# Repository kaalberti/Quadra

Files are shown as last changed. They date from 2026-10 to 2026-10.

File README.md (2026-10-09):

# Quadra

Active redesign: **ST3215 standard12V serial-bus servos +60 Wh conventional3S LiPo**.

- Current requirements/status:PROJECT.md and STATUS.md.
- Working leg CAD:mechanical/st3215-leg.scad; assembly preview:mechanical/st3215-leg.png.
- First-leg print/build instructions:docs/st3215-leg-build.md.
- Battery tray:mechanical/st3215-battery-tray.scad; provisional pack120 x50 x20 mm.
- Active single-servo feedback firmware: [bench guide](docs/st3215-feedback-bench.md), `firmware/st3215/`.
- Power/control architecture:electronics/st3215-power-plan.md.
- Buying list:docs/purchasing-bom.md; physical tests:PHYSICAL_TESTS.md.

These are untested working prototypes. Manufacturing/MFG-003 and existing
PWM firmware describe the previousMG996R design and are incompatible with
ST3215. Do not use them as the new build/programming instructions.

Read-only CAD artifact check: `node mechanical/verify-st3215-artifacts.mjs`.
Risk register and mitigation status: [design review](docs/design-review.md).

Verifier regression tests: `node --test mechanical/verify-st3215-artifacts.test.mjs` (in-memory changes; no CAD export).

- Complete working chassis assembly: [st3215-chassis.scad](mechanical/st3215-chassis.scad).
- Chassis build/layout: [build guide](docs/st3215-chassis-build.md).

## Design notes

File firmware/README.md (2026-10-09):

> ST3215 redesign: this is preserved MG996R/PCA9685 PWM firmware. It cannot control the selected serial-bus servos. Do not deploy it for the new leg. See ../electronics/st3215-power-plan.md.

Active ST3215 project: [st3215/README.md](st3215/README.md); [bench wiring/operation](../docs/st3215-feedback-bench.md).

# Individual-servo bench controller

FW-001 supports one explicitly armed servo at a time. This has been compiled
for the user-reported ESP32-S3 N16R8 (16MB flash/8MB OPI PSRAM), not flashed
or tested on hardware. The generic DevKitC pin mapping remains provisional.
Read ../electronics/bench-wiring.md first. Verify your actual board pins,
servo voltage and PSU capacity. Keep the servo rail OFF during setup/reset.

## Build and tests

The build wrapper refuses by default. For intentional MG996R/PCA9685 reference work only, use `firmware/build.ps1 -AllowLegacyPwm`; host tests remain `firmware/test.ps1`. The PowerShell console requires `-AllowLegacyPwm`, and direct Python console use requires `--allow-legacy-pwm`. These do not make this firmware compatible with ST3215. Direct PlatformIO/custom tools can bypass these entry-point guards.
For a new checkout on this Windows workstation, run
`firmware/setup-local-tools.ps1` first. It copies the existing PlatformIO
platform/packages locally and downloads the pinned, checksum-verified host
compiler if absent. It does not install PlatformIO globally. A different
workstation needs an existing compatible PlatformIO installation first.
The embedded build uses PlatformIO Core6.2.0 and project-local copies of
Espressif platform7.0.1, Arduino-ESP32 package3.20017.241212 and Xtensa
8.4.0. No third-party servo library is required. Wire is bundled with Arduino.
The local cache is ignored by Git; a clean checkout needs these build tools.

Host tests execute the same C++ controller, parser and PCA driver through
mock I/O. Portable Zig0.13.0 is used solely as a host C++ compiler, downloaded
from [the official distribution](https://ziglang.org/download/index.json).
Archive SHA256: d859994725ef9402381e557c60bb57497215682e355204d754ee3df75ee3c158.
All compiler/build caches stay in firmware/.pio-core or firmware/test-output.
Generated target: .pio/build/bench-s3/firmware.bin. No upload command is run.

## Serial commands —115200 baud, newline termination

| Command | Effect |
|---|---|
| `status` | Report state/fault/last channel and pulse; does not extend timeout |
| `arm 0` / `arm 1` / `arm 2` | From DISARMED, full-off all outputs, set selected channel1500us, then lower OE |
| `pulse 1450` .. `pulse 1550` | Change the armed channel within the narrow initial window |
| `keepalive` | Extend armed session if configuration and I2C are healthy |
| `disarm` | Raise OE immediately and write full-off; never clear a latched fault |
| `reset` | Raise OE and reinitialize; leave DISARMED if successful; rail OFF first |

An armed session requires a valid pulse or keepalive at least every1.5s.
Timeout, bus failure or invalid command while armed latches FAULT. Configuration
is checked every100ms while armed and before every move/keepalive. Recovery
requires diagnosis, physical power cutoff, then explicit reset and arm.
An arm command cannot change channels during an armed session; disarm first.
There are no joint-angle commands, calibration, IK, Wi-Fi or gait control.

Startup raises OE before I2C setup. The driver uses3.3V I2C at100kHz,
address0x40, MODE1=0x20 and MODE2=0x04. It programs prescale121 while asleep,
waits600us after waking, and individually full-offs all16 outputs before arm.
These sequences follow the [NXP PCA9685 datasheet](https://www.nxp.com/docs/en/data-sheet/PCA9685.pdf).
An existing sticky EXTCLK setting requires a PCA logic power cycle.

With a nominal25MHz oscillator, prescale121 yields50.0288Hz and4.88us/tick.
Requested1450/1500/1550us map to297/307/318ticks (1449.36/1498.16/1551.84us).
These are nominal values; measure actual PWM before widening travel or
attaching a horn. The narrow window is for an unmounted servo, not a known
safe range for the assembled leg. Register readback cannot verify physical
OE wiring, output pulse voltage, MCU lockup, or servo power/current.

Removing signals can leave a digital servo holding. Use the physical power
cutoff for isolation. No physical safety, fit or loaded-duty result is claimed.

## Supervised host console

Use the existing PlatformIO Python environment, for example:

```powershell
$env:PYTHONDONTWRITEBYTECODE='1'
& C:\Users\Kyle\.platformio\penv\Scripts\python.exe firmware/bench_console.py --port COM5 --allow-legacy-pwm
```

Substitute your verified port. Keep servo power OFF when opening the port:
some boards reset on serial connection despite DTR/RTS settings. The console
accepts a disarmed/faulted device and never arms automatically. A FAULT requires
diagnosis and the explicit operator command `reset rail-off`; this text is an
operator acknowledgement, not a voltage measurement.

Once `arm 0` is explicitly entered, the console sends keepalive every0.4s
while replies match the expected channel/pulse/state. `pulse 1450..1550`,
`status`, `disarm`, and `quit` are supported. Stay at the bench; console
keepalives continue while waiting for keyboard input. Use quit/disarm or the
physical cutoff before leaving. Loss of a reply within0.35s, unexpected state,
device reboot, invalid armed command or exit stops this session and attempts
disarm. It never reconnects or automatically recovers. If disarm cannot be
delivered, the MCU's1.5s command timeout remains the fallback.

Test without hardware:
`python -m unittest discover -s firmware/test -p test_console.py -v`.
These12 transport tests complement the12 C++ controller tests. The console
uses pyserial already present in the existing PlatformIO environment; it does
not enumerate/open ports during testing. No real serial session was performed.

## Offline calibration — FW-003

`include/joint_calibration.h` maps degrees to pulse width from two measured
anchors, in either direction. Usable angular limits must lie inside the anchor
interval; no extrapolation or silent clamping. Invalid/unmeasured profiles fail
without changing output. `joint-calibration.json` remains an unset recording
template, not loaded by firmware. No angle command is enabled on hardware.
Generic500..2500us validation bounds are only an absolute software screen,
not approved servo travel. Tests use synthetic profiles; never copy them to
hardware. Physical calibration and limits are listed in ../PHYSICAL_TESTS.md.

FW-007 adds `calibration_profiles.py` for measured JSON validation, offline
pulse previews and optional C++ header export. It requires all three measured
profiles and keeps every anchor/limit within1450..1550us. It never connects to
hardware or changes the firmware. The current unset template is rejected.
Workflow and commands: ../docs/measured-calibration-profiles.md.

FW-008 adds `offline_leg_plan.py` to run the existing C++ calibrated planner
against a requested foot reference position and explicit branch policy. It
returns a complete offline plan only if measured profiles, trial bounds and
bench pulse limits pass. Current unset records are rejected. No board connection
or powered commands are added. Workflow: ../docs/offline-leg-planner.md.

## Board-only diagnostic

`timing rail-off no-servos` is a manual serial-monitor command while DISARMED.
It temporarily drives only channel15 for3.3V timing capture on GPIO7, then
restores disabled/full-off outputs. FW-009 supports this explicit command in the
supervised console only while disarmed, with optional new-file `--timing-log`
JSONL capture. Do not run a serial monitor and console together. Wiring and limits:
../docs/board-pwm-timing-test.md. No physical capture or flash was performed here.

## Removable voltage diagnostic — ELEC-008

Manual serial command `voltage rail-off no-servos` works only while DISARMED.
GPIO8/ADC1_CH7 uses the provisional150k/10k perfboard divider and100nF filter.
Sixteen readings report nominal input voltage, ADC millivolts and sample spread;
no servo output is enabled and no battery cutoff is implemented. An armed
request trips the command fault. The input is not calibrated against physical
measurements and must be disconnected before ESP32 power is removed.
Wiring, voltage limit, buying delta and later comparison procedure:
[voltage input](../electronics/voltage-perfboard.md). No upload or powered test.

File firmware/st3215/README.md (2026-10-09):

# Active ST3215 bench firmware

Read [the wiring and operation guide](../../docs/st3215-feedback-bench.md).
This separate ESP32-S3 project supports single-servo ping, feedback and explicitly
acknowledged torque-off with readback. UART starts disabled. No motion, torque-enable,
broadcast or EEPROM command is exposed. Hardware testing and flashing remain pending.

Build: `./build.ps1`. Independent mock checks: `./test.ps1`.
Both reuse existing tools under parent `firmware/`; neither uploads firmware.

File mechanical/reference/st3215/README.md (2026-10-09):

# Public ST3215 reference files
Downloaded2026-10-09 from manufacturer wiki resource links:
- Drawing PDF/DXF:https://files.waveshare.com/upload/0/08/ST3215-2D.zip
- STEP:https://files.waveshare.com/upload/5/59/ST3215-3D.zip
- Linking page:https://www.waveshare.com/wiki/ST3215_Servo
The2022 drawing title isSCS215 despite its ST3215 resource filename/link.
Treat physical interfaces provisionally and check selected12V servo/wheel kit.
Working CAD uses a conservative envelope,not a claim of exact imported STEP fit.

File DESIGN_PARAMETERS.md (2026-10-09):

# Design parameters
Last updated:2026-10-09

## Robot and kinematics
LEGS = 4
DOF_PER_LEG = 3
DOF_TOTAL = 12
TARGET_OPERATING_MASS = 2.0 kg preferred
MAX_OPERATING_MASS = TBD; demonstrated servo/power duty
BODY_LENGTH = 175 mm PROVISIONAL
BODY_WIDTH = 160 mm PROVISIONAL
UPPER_LEG_LENGTH = 70 mm
LOWER_LEG_LENGTH = 85 mm
PROTOTYPE_J1_TO_J2_FORWARD = 85 mm PROVISIONAL
PROTOTYPE_J1_TO_J2_OUTWARD = 0 mm PROVISIONAL
PROTOTYPE_J1_TO_J2_VERTICAL = 0 mm
PROTOTYPE_NOMINAL_J1 = 0 deg
PROTOTYPE_NOMINAL_J2 = 44.0486 deg
PROTOTYPE_NOMINAL_J3 = 78.9786 deg
JOINT_LOADED_LIMITS = TBD
IK_BODY_FRAME = +x forward,+y left,+z up
POSITIVE_J1 = outward abduction
POSITIVE_J2 = upper leg forward
POSITIVE_J3 = knee flexion backward

## Actuator and mounting
SERVO_MODEL = ST3215 12V/30 kg.cm variant; user selected
SERVO_QUANTITY = 12
SERVO_CONTROL_INTERFACE = single-wire half-duplex TTL UART
SERVO_BUS_BAUD = 1000000 bit/s PROVISIONAL
SERVO_DRIVER = compatible TTL bus adapter; Waveshare Bus Servo Adapter A candidate
SERVO_OPERATING_VOLTAGE = 6..12.6 V manufacturer
SERVO_STALL_TORQUE_REFERENCE = 30 kgf.cm at12 V; not continuous torque
SERVO_STALL_CURRENT_REFERENCE = 2.7 A at12 V
SERVO_UNIT_MASS = TBD
SERVO_BODY_DRAWING_ENVELOPE = 45.22 x24.72 x35 mm PROVISIONAL
SERVO_SHAFT_OFFSET_FROM_END = 10.11 mm PROVISIONAL
SERVO_WHEEL_OD = 19.2 mm PROVISIONAL
SERVO_WHEEL_HOLE_PCD = 14 mm; four positions PROVISIONAL
SERVO_WHEEL_OVERALL_SPAN = 37.25 mm PROVISIONAL
SERVO_WHEEL_FACE_SYMMETRY = TBD
SERVO_WHEEL_SCREW_THREAD_AND_ENGAGEMENT = TBD
ST3215_FORK_INNER_PLANES = -23,+23 mm PROVISIONAL
ST3215_FORK_PLATE_THICKNESS = 5 mm
ST3215_WHEEL_FRONT_FACE_DISTANCE = 18.625 mm PROVISIONAL
ST3215_WHEEL_REAR_FACE_DISTANCE = 18.625 mm PROVISIONAL; positive magnitude
ST3215_WHEEL_FRONT_SPACER = 4.375 mm PROVISIONAL; 23 minus front face
ST3215_WHEEL_REAR_SPACER = 4.375 mm PROVISIONAL; 23 minus rear face
ST3215_CASE_CLAMP_POCKET = 25.52 x35.8 mm PROVISIONAL
ST3215_CLAMP_FIT_COUPON_GRIP = 29 mm PROVISIONAL
ST3215_CLAMP_FIT_COUPON_POCKET = 25.52 x29.8 mm PROVISIONAL
ST3215_CASE_CLAMP_SPLIT_GAP = 1 mm PROVISIONAL
ST3215_WORKING_CAD = mechanical/st3215-leg.scad
ST3215_LEG_PRINT_PIECES = 16 PROVISIONAL
PHYSICAL_FIT_VALIDATED = false
POWERED_LEG_VALIDATED = false
CURRENT_MANUFACTURING_PACK = NONE for ST3215

## Power
BATTERY_CHEMISTRY = conventional LiPo PROVISIONAL
BATTERY_CELL_COUNT = 3S
BATTERY_ENERGY = 60 Wh user reported
BATTERY_NOMINAL_VOLTAGE = 11.1 V PROVISIONAL
BATTERY_MAX_VOLTAGE = 12.6 V
BATTERY_CAPACITY = approximately5.4 Ah DERIVED; label unverified
BATTERY_DISCHARGE_RATING = TBD
BATTERY_DIMENSIONS = 120 x50 x20 mm PROVISIONAL user supplied
BATTERY_MASS = TBD
BATTERY_CONNECTOR = TBD
BATTERY_LOCATION = low central removable; actual packaging TBD
SERVO_POWER_ARCHITECTURE = protected switched3S battery bus
SERVO_SUPPLY_VOLTAGE = battery voltage; maximum12.6 V
SERVO_MAIN_DISTRIBUTION_CAPACITY_SCREEN = 40 A PROVISIONAL; not demand
SERVO_THREE_JOINT_STALL_SUM = 8.1 A reference
SERVO_TWELVE_JOINT_STALL_SUM = 32.4 A reference
MAIN_FUSE = TBD; coordinated with pack,wires,connectors
BRANCH_PROTECTION = TBD
LOGIC_SUPPLY = regulated5 V buck from3S; module TBD
LOGIC_VOLTAGE = 3.3 V ESP32
BENCH_SERVO_SUPPLY = 12.0 V PROVISIONAL one-servo tests
AVAILABLE_BENCH_SUPPLY_MAX_VOLTAGE = 60 V user reported
AVAILABLE_BENCH_SUPPLY_CURRENT = 5 A user reported
BATTERY_SOFTWARE_STOP_THRESHOLD = 10.5 V PROVISIONAL loaded
BATTERY_WARNING_THRESHOLD = 10.8 V PROVISIONAL
BATTERY_CELL_MONITOR = 3S balance-lead alarm; threshold/part TBD
BATTERY_PROTECTION_IMPLEMENTED = false

## Electronics and sensors
MCU = ESP32-S3
OWNED_MCU_BOARD = ESP32-S3 N16R8; header layout unverified
OWNED_PWM_BOARD = Adafruit PCA9685; unused in current actuator design
SERVO_BUS_GPIO = TBD
SERVO_BENCH_GPIO_ALLOWED = distinct GPIO4..7; manual selection with rail off
SERVO_BENCH_CAPABILITY = ping/feedback/torque-off readback only; no motion
SERVO_BENCH_PHYSICALLY_VALIDATED = false
SERVO_IDS = FL1..3; FR4..6; RL7..9; RR10..12 PROVISIONAL
IMU = 6-axis breakout TBD
RANGE_SENSOR = forward ToF breakout TBD; later stage
ELECTRONICS_PROTOTYPE_ASSEMBLY = perfboard and modules
ELECTRONICS_FINAL_ASSEMBLY = SMT consideration; TBD
ELECTRONICS_PREFERRED_SUPPLIER = DigiKey
CUSTOM_PCB = DEFERRED
VOLTAGE_DIAGNOSTIC_DIVIDER = 150 kOhm /10 kOhm,100 nF PROVISIONAL
VOLTAGE_DIAGNOSTIC_GPIO = 8 PROVISIONAL
VOLTAGE_DIAGNOSTIC_INPUT_RANGE = 0..25.2 V positive; manual power sequencing only
VOLTAGE_DIAGNOSTIC_PHYSICAL_CALIBRATED = false

## Printing and budget
AVAILABLE_PRINTER = Creality K2 Pro user-reported access
NOZZLE_DIAMETER = 0.4 mm
LAYER_HEIGHT = 0.2 mm
PRIMARY_MATERIAL = PLA+ /PETG
DEFAULT_STRUCTURAL_WALL = 3 mm PROVISIONAL
DEFAULT_JOINT_FASTENER = M3
TOTAL_REV_A_BUDGET_TARGET = NZ$500–800
TOTAL_REV_A_BUDGET_MAX = NZ$1000
SERVO_UNIT_COST_TARGET = NZ$25–35
SERVO_UNIT_COST_SOFT_MAX = NZ$50
ACTUATOR_TOTAL_TARGET = NZ$300–420
ST3215_LANDED_PRICE = TBD

BATTERY_TRAY_INTERNAL_ENVELOPE = 122 x52 mm PROVISIONAL
BATTERY_TRAY_PRINT_ENVELOPE = 134 x66 x11 mm
BATTERY_TRAY_PADDING = 1 mm PROVISIONAL
BATTERY_TRAY_STRAPS = 2 reusable15 mm straps; length >=250 mm PROVISIONAL
BATTERY_TRAY_MOUNTING = fourM3 holes; chassis placement TBD

## ST3215 chassis layout
CHASSIS_CAD = mechanical/st3215-chassis.scad
CHASSIS_HIP_ORIGINS = FL[115,50,0];FR[115,-50,0];RL[-115,50,0];RR[-115,-50,0] mm
CHASSIS_FRONT_LEG_YAW = 0 deg
CHASSIS_REAR_LEG_YAW = 180 deg
CHASSIS_OUTWARD_J1_SOURCE_SIGN = FL+;FR-;RL-;RR+
CHASSIS_PRINT_ENVELOPE = 175 x160 x42 mm
CHASSIS_FLOOR_Z = -48..-43 mm
CHASSIS_WALL_THICKNESS = 5 mm
CHASSIS_HUB_RELIEF_DIAMETER = 34 mm
CHASSIS_DECK_ENVELOPE = 140 x140 x4 mm
CHASSIS_DECK_UNDERSIDE_Z = 8 mm
CHASSIS_RISERS = four10 mm diameter x51 mm; M3 bore
CHASSIS_BATTERY_CENTER = [0,0,-29] mm PROVISIONAL
CHASSIS_BATTERY_TO_DECK_CLEARANCE = 27 mm PROVISIONAL; no leads
CHASSIS_NOMINAL_FOOT_REFERENCE_SPACING = 400 x100 mm
CHASSIS_NOMINAL_FLOOR_GROUND_CLEARANCE = 72 mm; excludes hardware/pads
CHASSIS_SOLID_PETG_MASS = approximately331 g DERIVED; excludes legs/tray/hardware
CHASSIS_PHYSICAL_VALIDATED = false
ROBOT_INSTALLED_PRINT_PIECES = 71 PROVISIONAL; includes battery tray

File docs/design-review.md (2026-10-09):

# Current design review — ST3215 / 3S prototype

Reviewed: 2026-10-09. Scope: current printable one-leg CAD, provisional battery
tray, power/control plan, buying BOM, validation checker and physical-test plan.
This register records findings; it does not approve hardware for powered use.

The architecture is a plausible affordable prototype direction. Its main gaps
are real servo interfaces, protected electrical implementation and control
firmware. Additional detailed structural analysis is unlikely to help as much
as testing one servo kit and one printed leg. A complete walking robot has not
yet been designed or qualified.

## Evidence and limits

- [Leg CAD](../mechanical/st3215-leg.scad), [build guide](st3215-leg-build.md)
  and [validation report](../mechanical/st3215-leg-check.json): eight leg meshes and two alternative fit coupons, axis/contact checks and three sampled collision poses passed.
- [Battery tray](../mechanical/st3215-battery-tray.scad) and
  [tray guide](st3215-battery-tray.md): printable geometry, not verified pack fit.
- [Power plan](../electronics/st3215-power-plan.md), [BOM](purchasing-bom.md)
  and [physical tests](../PHYSICAL_TESTS.md): planned components and tests,
  not implemented protection, actual current measurements or completed tests.
- Current report hashes match both CAD sources, the validation generator, ten part/coupon STLs and tray STL.
  This checks artifact identity; it does not repeat or extend the CAD checks.
- No servo, battery, print, firmware or loaded leg has been physically validated.

## Risks and checks

Priority is the milestone affected, rather than a speculative numerical score.
A later-stage issue does not block current documentation or a cheap fit coupon.

| ID / resolve before | Evidence and risk | Consequence | Smallest useful check or action |
| --- | --- | --- | --- |
| R1 — bulk leg printing | Clamp pocket defaults to 35.8 mm while the referenced main shell band is about 29 mm; drawing-to-actual case shape remains uncertain. The 1 mm split cannot close that difference. Short tail grip also depends on friction and print creep. | Loose servo, crushed case if overtightened, or blocked connector. | Obtain one kit; measure the actual grip band and ports; print one clamp coupon. Adjust the grip parameter or use fitted liners, then check retention without case distortion. |
| R2 — assembled powered leg | Rear wheel/support behavior, wheel face positions and supplied screws are unverified. Front/rear spacers now adjust independently; their default 4.375 mm values still assume symmetric faces. | Binding, bearing preload, stripped threads or a fork attached to a stationary case feature. | Verify both output interfaces; measure each side separately; hand-assemble a fork with correct screw engagement and free movement before power. |
| R3 — motion beyond sampled poses | Collision checks cover three poses and simplified bodies; they omit real cable bends, protruding fasteners and spacer-ring interactions. | Cable damage or a hard mechanical stop while the motor drives. | Route actual cables; move the supported unpowered leg through a conservative intended range; establish limits from observed clearance. Check additional CAD poses only where useful. |
| R4 — loaded leg | Long hip bridge, fork plates and tail clamps have no printed/load evidence. Layer direction, support removal, bolt tightening and warm plastic can affect stiffness. | Deflection, slipping joints or print failure despite a valid STL. | Slice with suitable orientation/supports; inspect the first prints, then apply representative supported foot load and check movement/loosening. Revise locally if needed; no FEA required now. |
| R5 — battery-powered multi-servo test | 60 Wh and the assumed pack size do not establish discharge rating, cell balance, mass or condition. | Excessive sag, hot wiring or damaged cells. | Read the actual label/specification, inspect and balance-check the pack; verify connector ratings and measure staged load/sag. Use a compatible balance charger. |
| R6 — any powered test; scale before multiple servos | Harness, fuses, switch and buck are not selected. The proposed adapter is rated only 5 A; one-leg stall reference is 8.1 A. Three-wire injection can accidentally put aggregate current through small cables. | Overheated connectors/board, shorts or MCU damage. | Fuse the initial single-servo setup; verify polarity/pinout. Design rated parallel power branches with a shared signal ground and explicit injection wiring before scaling. Do not use adapter/perfboard as the main power distributor. |
| R7 — unrestricted battery motion | Full 3S charge is 12.6 V, equal to the published servo upper operating limit. Regeneration/transients and logic supply behavior are untested. | Servo overvoltage, resets or uncontrolled commands after brownout. | Start at current-limited 12.0 V on the bench; verify separate logic regulation and USB/power paths. Investigate supply excursions during starts/stops before unrestricted battery use; a multimeter alone cannot establish fast peak voltage. |
| R8 — unattended or prolonged battery operation | No low-battery protection works yet. Pack voltage can hide a weak cell. Existing manual ADC sense requires sense-positive disconnection before MCU power-off. | Overdischarge or back-powering an unpowered ESP32 input. | Use individual-cell monitoring and manual observation initially; implement supported low-battery stop and safe off-state sensing before leaving the pack connected. Qualify thresholds against the actual pack. |
| R9 — first commanded motion | Legacy firmware drives PWM servos. Separate ST3215 feedback/off bench is compiled and mock-tested; motion, direction, offsets, joint limits and powered fault behavior remain unimplemented/unverified. Default IDs may conflict; lost communication behavior is unqualified. | Unexpected movement, continued holding/heating, or collapse on torque removal. | Commission one unmounted servo and one unique ID at a time. Verify feedback, startup, timeouts, recovery and torque release; support the leg/robot during calibration and shutdown. |
| R10 — choosing final mass or walking duty | Stall torque is not a continuous torque rating. Current total robot mass and sustained demand at discharged-pack voltage are unknown. | A robot that stands briefly but overheats, sags or cannot walk reliably. | Weigh the actual assembly; perform one useful stance torque estimate and supported loaded-leg duty test. Adjust stance/geometry or mass if measurements require it; do not treat 2 kg as a qualified limit. |
| R11 — standing on four legs | A working ST3215 chassis/rotated leg layout now exists with provisional battery/board spaces and geometric four-foot support. Actual mass/COM, hardware fit and loaded motion remain untested. Flat foot contact is aligned to the nominal stance only. | Inter-leg interference, tipping, insufficient ground clearance or edge contact/slip. | Lay out four legs and actual masses, revise kinematics for the new datum, and check a simple supported stance/weight shift before crawl. Test inexpensive foot pads if slipping appears. |
| R12 — relying on automated qualification | Link/hip dimensions now drive geometry and parameter perturbations are checked. Nominal pose qualification and some fixed interface dimensions remain deliberately specific to this revision. Tray source and generator are now hash-bound; full swept and physical qualification remain outside these checks. Existing legacy firmware/release outputs remain in the repo. | A future edit or old workflow can appear valid while describing different hardware. | Read-only artifact verification and explicit legacy build/console guards are implemented. Keep geometry/checks coupled when revising CAD; use fit checks after exports. Direct PlatformIO invocation or custom serial tools can bypass these entry-point guards. |
| R13 — ordering all twelve servos | Exact variant, kit contents and landed NZ cost are not confirmed. Quantity multiplies small price differences; power hardware and charger add cost. | Budget overrun or twelve incompatible kits. | Confirm standard 12 V variant and wheel kit with one sample, then price the complete quantity-adjusted BOM including freight/tax before bulk ordering. No supplier contact is needed for this review. |

Manufacturer basis for R6: [Bus Servo Adapter A FAQ](https://docs.waveshare.com/Bus_Servo_Adapter_A/FAQ)
states 5 A maximum board current, no onboard voltage regulation and unique servo
IDs. This supports the existing separate power-distribution direction.
Manufacturer basis for R7/R10: [ST3215 documentation](https://www.waveshare.com/wiki/ST3215_Servo)
and [product specifications](https://www.waveshare.com/product/st3215-servo.htm).
The standard 12 V model lists 6–12.6 V operation, 30 kgf.cm stall torque and
2.7 A stall current at 12 V. These are reference limits, not measured robot duty.

## Assumptions to keep explicit

| ID | Working assumption | How it will be resolved |
| --- | --- | --- |
| A1 | Standard 12 V ST3215, not the 7.4 V or HS variant; published drawing/model matches the purchased kit. The downloaded drawing is labelled SCS215 despite its ST3215 filename. | Compare one actual kit with the drawing and CAD before repeated prints/orders. |
| A2 | Both sides provide compatible wheel interfaces usable for the supported fork; actual kit includes suitable wheels/fasteners. | Inspect rear support behavior and supplied hardware; do not infer it from the case boss alone. |
| A3 | Conventional 3S LiPo, about 60 Wh; 120 x 50 x 20 mm is only the provisional pouch envelope. | Measure label, pack, leads and connector; record mass, condition and discharge rating. No LiHV substitution. |
| A4 | 70/85 mm links and 85 mm hip forward offset provide useful first-leg geometry; nominal foot axial datum is now 0 mm. | Test one leg and then check complete chassis packaging and calibrated kinematics. |
| A5 | Printer/material tolerances, support removal and plain bolt hardware allow the proposed fit. | Slice and print coupons/first parts; inspect actual clearances and tightening stack. CAD fit is not printer fit. |
| A6 | Extra weight is acceptable only where loaded servo/current/temperature tests support it. | Maintain an actual mass tally. Old MG996R mass estimates do not qualify the new robot. |
| A7 | Initial operation is remotely commanded, slow and on a level indoor surface. | Validate static stance and crawl before adding terrain or autonomous operation. |
| A8 | Joint feedback improves control but does not provide calibrated foot force or room position. 4096 counts/revolution is resolution, not guaranteed angular accuracy. | Check measured angles/load behavior; allow for backlash, compliance and foot slip. |
| A9 | Owned 5 A PSU is adequate for staged individual-servo tests, not simultaneous leg stall demand. Runtime estimates are illustrative. | Measure actual supported motion current; qualify supply behavior and battery runtime later. |

## Future work, in useful order

1. **Verify one servo kit and first printed interfaces.** Measure case/wheels,
   revise clamp/spacers if needed, and hand-assemble a supported unpowered leg.
   Pass: snug retention, free output movement and usable screw/cable access.
2. **Bring up one ST3215 safely.** Define the adapter wiring and implement minimal
   ESP32 bus control, feedback, unique IDs and safe startup/fault handling.
   Pass: repeatable commanded/measured positions and intentional supported shutdown.
3. **Complete protected power and battery implementation.** Select affordable
   rated distribution, fuses, disconnect, logic buck and cell monitoring; keep
   high-current paths off perfboard. Pass: checked wiring/polarity and staged
   current/sag/temperature tests using the actual pack specifications.
4. **Prove one leg under representative load.** Calibrate limits and new kinematics,
   measure stiffness, slip, servo heat and duty current. Pass: a useful repeated
   supported movement cycle without binding, brownout or progressive loosening.
5. **Integrate the four-leg chassis.** Place actual battery/electronics, establish
   handed assemblies, weight/support geometry and wiring access, then prepare a
   current manufacturing checkpoint. Pass: assembleable layout and supported stance.
6. **Progress through standing, weight shifts and slow crawl.** Prove stop/recovery
   behavior first. Pass: repeatable remote movement on the intended floor.
7. **Add sensors when movement is dependable.** Start with IMU and power monitoring,
   then forward ranging for simple obstacle avoidance. IMU yaw drift, foot slip
   and a narrow forward range view limit navigation; mapping needs a separate
   localization plan if it becomes a real requirement.

These are future milestones, not tasks executed by this review. Detailed physical
acceptance checks already live in [PHYSICAL_TESTS.md](../PHYSICAL_TESTS.md).

## Practical improvements

**At the next relevant build:** make clamp grip and each side's spacer thickness
match measured hardware; retain easy screw/tool access; add simple cable strain
relief; smooth tray/strap edges and keep bolt heads away from the pouch. The tray
is an open holder, not an impact enclosure. Include lead clearance, soft padding
and accessible removal/disconnect in chassis placement.

**After the first leg works:** consider cheap locking nuts if joints loosen,
standardize fasteners where the real stack permits, tune supports/orientation
from slicer results and add replaceable grippy foot pads if needed. Shorten the
hip offset or add a local rib only if packaging or observed deflection warrants
it. Reduce duplicated CAD/checker dimensions and separate exports from read-only
verification to avoid accidental changes during a review.

**Defer:** exhaustive load cases, mass shaving, appearance, integrated SMT/PCB
hardware, active ankles, foot-force sensors and mapped navigation. They should
follow a demonstrated need. Perfboard auxiliaries, commodity modules and one-kit
experiments remain the cheaper path to a working first prototype.

## Mitigations implemented without hardware — RISK-001

- **R12 partially mitigated:** `node mechanical/verify-st3215-artifacts.mjs`
  checks both CAD sources, the generator and every expected STL against the
  fresh report, including exact part names, paths and quantities. It is read-only;
  stale or incomplete evidence fails. The generator checks both sources again
  after the final export before recording their hashes. These hashes establish
  recorded artifact identity, not physical safety or correctness of every checker.
- **R9/R12 accidental legacy entry-point use reduced:** PowerShell build/console
  wrappers now refuse unless `-AllowLegacyPwm` is explicit. The Python console
  independently requires `--allow-legacy-pwm` before importing serial or opening
  a port. Intentional legacy work remains possible. Direct PlatformIO/custom
  serial tools are outside these guards. Separate ST3215 feedback/off bench now
  starts with UART disabled and excludes motion/enable/EEPROM commands; protocol
  and console checks pass. Physical commissioning is still pending; see
  [bench guide](st3215-feedback-bench.md).
- Geometry and power architecture are unchanged. R1–R11 physical/electrical
  qualification and R13 landed-price checks remain open; physical geometry/fit assumptions still need measured verification.

Validation: fresh mesh/bore/contact checks and all six sampled intersections passed.
Twelve artifact tests, twenty-one mocked console regressions, Python CLI refusal
and both PowerShell preflight refusals passed. Verifier execution left all source,
report and STL bytes unchanged. No serial port was opened or hardware flashed.

## Mechanical refinement — MEC-171

R1 has a cheap printable check: two29 mm grip-band clamp halves with the same
mounting pattern as the default35 mm version. This reduces fit iteration cost;
it does not establish the actual band shape, port clearance or retention force.
R2 no longer requires equal front/rear spacer thicknesses: each is derived from
its separately configurable wheel face. Both defaults remain provisional.
R12 link/hip dimension drift is reduced by shared CAD parameters and independent
mesh perturbation checks. Nominal geometry, bought hardware and sixteen installed
prints remain unchanged; the coupons are alternatives, not additional leg parts.

## Chassis layout — MEC-172

R11 packaging uncertainty is reduced by a printable four-leg layout with matching
hip fixture holes, rotating-hub reliefs, low central battery and removable generic
electronics deck. Two clearance poses and a geometric four-foot support check
are available. This does not establish loaded strength, actual COM, three-foot
support or walking range. Real electronics, battery leads and bolt protrusions
remain physical checks. See [chassis build guide](st3215-chassis-build.md).
The widened175 x160 mm body and long carrier footprint trade compactness for
reuse and simple assembly; mass/servo duty still need qualification.

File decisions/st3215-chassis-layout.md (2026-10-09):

# ST3215 chassis layout — MEC-172

Date: 2026-10-09. Working geometry; actual hardware fit and mass unqualified.

Use a175 x160 mm floor/end-wall chassis with identical current leg parts and
rear leg assemblies rotated180 degrees about z. Keep the existing70/85 mm links
and85 mm hip carrier offset. Do not create handed servo brackets or shorten
carriers before the first real interface test.

The earlier nominal180 x110 mm body target is widened for the existing60 mm-wide
J1 fixture plates, two hip axes100 mm apart and accessible end-wall hardware.
The end-wall fixture holes span152 mm across y; a160 mm wall leaves room for the
provisional M3 washers. Hip axes at x=+/-115 mm place the mounting interfaces at
x=+/-87.5 mm, leaving a165 mm central bay for the134 mm battery tray.
The slight reduction to175 mm body length comes from this matching mount stack.

Place the battery low on the floor, centred in x/y. Raise a removable140 mm-square
generic electronics deck on four printed spacers rather than buying special
standoffs or locking an unknown board hole pattern. Use commodity M3 through
bolts, slots and insulating board mounts after measuring the real modules.

End walls need34 mm reliefs at the rotating hip hubs; a solid matching wall would
interfere with the fork. Verify this interface using actual exported hip meshes.
The layout is intentionally long: nominal foot references span400 x100 mm.
The wide body/long carriers are acceptable for an affordable static/crawl trial;
compactness can be revisited if physical loading or packaging justifies it.

Consequences: body-to-leg transforms and outward-J1 signs differ across the four
positions and must be implemented/calibrated later. Actual centre of mass and
sustained torque remain unknown. No gait range, loaded limit, motor upgrade or
manufacturing release follows from this layout alone.

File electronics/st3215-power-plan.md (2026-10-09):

# ST3215 power and control plan

Use the **12V ST3215**,6..12.6V permitted input. Conventional3S LiPo is
11.1V nominal,12.6V full; no LiHV pack/overcharging substitution.

Battery -> correctly sized main fuse near pack -> rated accessible servo-power
switch/disconnect -> rated distribution -> parallel leg/servo power branches.
Battery also feeds an independently fused5V logic buck -> ESP32/auxiliary logic.
ESP32 UART -> compatible half-duplex TTL adapter -> signal bus to12 servo IDs.
Common signal/power ground; motor current returns through distribution,not MCU.
Adapter needs appropriate supply as documented; never put12.6V on UART/5V pins.

Separate data chaining from current distribution. Supplied three-wire cables
can combine both; final harness must avoid backfeeding duplicate positives and
must establish actual connector/pinout/current capability. Verify polarity with
meter,not wire colour. Do not carry32A through adapter,DC barrel,perfboard or
first daisy-chain lead. Manufacturer FAQ rates Bus Servo Adapter A at5A maximum; this is not a main-distribution path.
Power-injection harness and connector selection remain a subsequent bounded task.

Planning checks:2.7A per stalled servo at 12 V;8.1A per leg,32.4A all12.
40A main capacity screen provides provisional headroom; actual gait demand
must be measured. Main/branch fuse and wire sizes remain TBD until pack and
connector ratings and cable lengths are known. A fuse must protect the wires,
not merely equal an estimated motor total.

60 Wh nominal energy implies about5.4 Ah at11.1V. Pack must have a documented
appropriate discharge rating,healthy cells,balance connector and undamaged
leads. Example10C x5.4 Ah=54A advertised; verify manufacturer's continuous/peak
ratings and real voltage sag. Pack envelope120 x50 x20 mm is user-provided provisional;mass and actual fit remain TBD.
Illustrative80% usable60 Wh gives48 Wh: at40W average ~72min,at80W ~36min.
Neither is a measured runtime; weight and gait materially affect demand.

Start one unmounted servo at12.0V from current-limited bench PSU,with proper
fuse and known adapter wiring. Existing5A PSU can serve this initial trial;
three-servo stall screen8.1A exceeds it. No connected-leg motion before calibrated
angles,mechanical range and bus startup/shutdown behavior are verified.

Battery operating protection is not implemented. Plan pack warning10.8V and
controlled stop10.5V loaded provisionally,plus individual-cell balance-lead
monitoring; pack voltage cannot reveal an imbalanced weak cell. Thresholds need
pack-specific trials. A supported controlled stop precedes power removal because
cutting torque can collapse the robot. Provide a manual power disconnect regardless.
Do not rely on servo minimum6V to protect a3S battery from overdischarge.

Full charge sits at servo's12.6V stated maximum. Check bus transients during
starts/deceleration,local bulk capacitance and regenerative behavior before
unrestricted motion. Do not assume an arbitrary TVS clamp guarantees12.6V.
Use compatible balance charger/storage settings; bench PSU is not a balance charger.

Existing150k/10k voltage input can measure3S within its25.2V screen, but it is
manual/disarmed and requires disconnecting sense positive before ESP power-off.
An always-connected battery input needs revised off-state isolation/protection.
Old PWM firmware must not be flashed for ST3215 control; bus firmware is pending.

References:
https://www.waveshare.com/wiki/ST3215_Servo
https://docs.waveshare.com/Bus_Servo_Adapter_A
https://docs.waveshare.com/Bus_Servo_Adapter_A/Product-Wiring-Example
https://docs.waveshare.com/Bus_Servo_Adapter_A/FAQ

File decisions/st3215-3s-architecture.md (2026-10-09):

# ST3215 and3S power architecture — MEC-170

User selected ST3215 and inexpensive60Wh3S LiPo. Choose the standard12V
variant,not7.4V or HS. This supersedes MG996R,PCA9685 leg PWM,and the5.2V
servo BEC/buffer direction. Existing hardware remains owned; previous firmware
and manufacturing files remain historical references,not active ST3215 outputs.

Direct3S power is within the manufacturer's6..12.6V input range. Use a separate
5V logic buck and compatible half-duplex TTL adapter. Avoid high servo current
through the adapter/barrel jack; use external protected distribution.
60 Wh/11.1V =5.405 Ah nominal,not verified capacity or discharge capability.
12 x2.7A=32.4A stall sum at 12 V;40A distribution capacity is a provisional screen,
not a measured continuous load or chosen fuse. Check actual pack current rating
before use. A genuine10C5.4 Ah pack would advertise54A; a low-rate pack might
be unsuitable despite equal energy. Fuse selection waits for real ratings.

Dual-side wheels permit shorter output forks and removal of old external624
bearings/pivots. Adjustable split clamps avoid undocumented case screw threads.
The manufacturer's2022 drawing downloaded from the ST3215 wiki is titledSCS215:
use it provisionally,then verify selected servo and supplied wheels physically.
The rear wheel/bearing behavior and support capability are untested.

Keep70/85 mm links and85 mm forward hip spacing initially; pitch/foot plane is
now0 mm axial rather than the MG996R32 mm outward datum. Offline kinematics must
use the new datum; old CAD/calibration/source correspondence is not transferable.
A0.751Nm earlier2.2 kg demanding-pose estimate is below2.942Nm advertised12V
stall,but revised mass,voltage,stance and thermal duty remain unmeasured. No
maximum mass,loaded range or continuous torque is approved by this comparison.

Battery mass is unknown;120 x50 x20 mm envelope user-provided provisionally: retire the old150g allowance and2.178 kg
estimate as current estimates. Do not build a tight battery tray from60 Wh alone.
No actuator buying quantity or physical success inferred. Obtain/test one servo
first; exact twelve-unit landed cost remains TBD under existing budget.

Sources accessed2026-10-09:
- https://www.waveshare.com/wiki/ST3215_Servo
- https://www.waveshare.com/product/st3215-servo.htm
- https://files.waveshare.com/upload/0/08/ST3215-2D.zip
- https://files.waveshare.com/upload/5/59/ST3215-3D.zip
- https://docs.waveshare.com/Bus_Servo_Adapter_A

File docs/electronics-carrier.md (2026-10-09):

> Superseded MG996R/PWM design reference. Active design is ST3215 12V with3S power; see README.md,docs/st3215-leg-build.md and electronics/st3215-power-plan.md. These quantities,interfaces and mass estimates are not the current ST3215 design.

# Removable two-tier electronics carrier — MEC-167

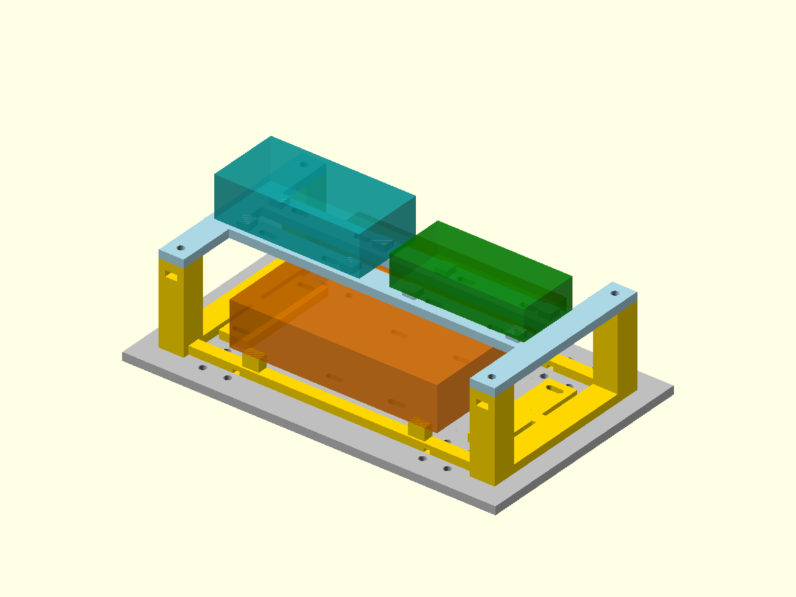
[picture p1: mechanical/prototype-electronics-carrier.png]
Working carrier assembly


Working CAD:mechanical/prototype-electronics-carrier.scad. It uses the optional
MEC-166 electronics deck and keeps all16 chassis fixing paths accessible.
The amber lower block is the100 x80mm PAD2 reservation; teal/green upper blocks
are the unmeasured ESP32/PCA9685 envelopes. Blocks show reserved occupied space,
not exact boards or released fit. The mounting system remains optional.

## Print and assemble

Print one prototype-electronics-carrier-base.stl and one
prototype-electronics-carrier-shelf.stl, both flat as exported. Each is one
closed connected mesh and fits the K2 Pro bed:162 x88mm planform; base40mm tall,
shelf7mm tall. Use PETG with0.4mm nozzle/0.2mm layers and conservative walls.
The base has side-loading nut pockets with short bridged roofs; inspect/clear
these before inserting nuts. Slicer mass supersedes the solid CAD estimate.
No structural FEA or load qualification is implied. Remove the upper shelf
for access to the lower board and underside wiring.

Fit four M3 nuts through the outside-facing base pockets, flats aligned with
the5.9mm channel. Place the shelf on its columns, then use four M3 x12 bolts
with one ordinary washer each. Check printed pockets and screw engagement;
do not force a nut into a tight print. Nominal screws stay inside the columns,
without protruding into the deck. These are additional option hardware.

Two narrow ties,width<=2.5mm,attach the base through paired deck/base slots at
x=+/-60,y=+/-20mm. Start with ties about150mm or longer and confirm loop length.
Thread before closing the chassis. Underside relief channels allow two more
lower-PCB ties at x=+/-46mm. Each must cross a bare PCB margin without pinching
jumpers. No purchased PCB mounting-hole pattern is assumed.

Upper shelf strap lanes x=-55,-25,25,55mm through y=+/-10mm allow up to four
board ties. Choose only lanes over actual blank PCB regions or safe insulating
adapters; move boards or use verified mounting holes if a lane crosses hardware.
Never strap over components,solder,USB sockets or the ESP32 antenna.
Conditional maximum:eight narrow ties (two carrier,two lower board,four upper
boards), replacing the earlier generic four-tie mount allowance if adopted.
Leg cable ties are separate. Reuse stock rather than buying another pack.

## Geometry and service access

Relative to carrier bottom, lower-PCB underside is10mm, giving6mm above its
rail surfaces for solder/jumpers. The populated reservation includes1.6mm PCB
plus20mm component height and ends at31.6mm. Shelf underside40mm leaves8.4mm
nominal separation. Upper PCB undersides47mm leave3mm above shelf rails.
Actual solder/socket/header height and wires may need different support pads.

ESP32 claim70 x35 x20mm is centred x=-40; PCA claim65 x30 x15mm is centred
x=40. Nominal edge gap12.5mm. Verify USB/antenna/header access on actual boards.
No exact PCB holes,connectors,battery/BEC or power-star mounting is asserted.
Motor power uses the separate rated star,never this perfboard or PCA tracks.
Route and restrain wiring before any joint motion.

## Checks and limits

Run `node mechanical/check-electronics-carrier.mjs`. Both meshes are closed,
connected and bed-oriented.384 hole,nut-entry,strap,underside-channel,board-pad
and chassis fixing paths pass. Fresh CGAL intersection with all three nominal
board envelopes is empty;0.001mm relief excludes intended support-face contact.
The checker rejects CGAL errors/warnings and unexpected probe meshes.
Preview rendered and visually inspected. Full servo travel/cable sweep and
printed stiffness/physical fit have not been tested.

Combined solid PETG CAD mass is79.8g,not an actual print measurement. The robot
screen already exceeds2kg at2.178kg. This option is not added to the93-piece
robot manifest or mass record. If adopted,use the electronics deck instead of
the original deck,add these two prints and measured hardware/masses,and recheck
complete mass and demonstrated servo capacity. Manufacturing remains the MFG-003 first-leg checkpoint.

The simpler [single-level sleds](electronics-sleds.md) are now preferred for
the working prototype because they fit the same nominal boards with less
material,height and M3 hardware. This stack remains a fallback if actual
connector/wire fit needs it; do not print/buy both options automatically.

Current [mass policy](servo-qualified-mass.md):2kg is preferred;heavier is allowed within demonstrated servo/power duty. No physical qualification is recorded.

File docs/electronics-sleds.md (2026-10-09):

> Superseded MG996R/PWM design reference. Active design is ST3215 12V with3S power; see README.md,docs/st3215-leg-build.md and electronics/st3215-power-plan.md. These quantities,interfaces and mass estimates are not the current ST3215 design.

# Simple single-level electronics mounts — MEC-168

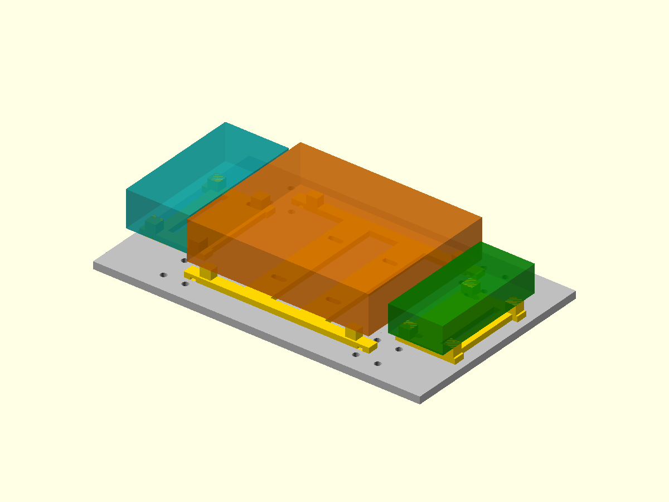
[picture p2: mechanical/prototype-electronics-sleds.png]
Single-level working layout


Preferred working mount option: three small insulating frames on the existing
180 x110mm electronics deck. This replaces the need for a stacked carrier
unless actual board/connector fit proves otherwise. Provisional controller
space claims are rotated90degrees; no actual PCB hole pattern is assumed.
No battery, BEC or motor-power star is packaged by this option.

Source:mechanical/prototype-electronics-sleds.scad.
Print one each of prototype-electronics-sled-perfboard.stl,
prototype-electronics-sled-esp32.stl and prototype-electronics-sled-pca9685.stl.
All print flat on their exported bed faces,8mm tall,without nut pockets or
added M3 hardware. Use PETG,0.4mm nozzle/0.2mm layers and conservative walls.
Inspect narrow slots and underside tie relief. Dry fit before buying/printing
any quantity. Boards rest on insulating pads8mm above the deck,5mm above rails;
keep solder/insulated jumpers within that underside space.

## Position and secure

| Frame | Centre relative to deck | Board space reservation |
| --- | --- | --- |
| ESP32 | x=-70,y=0 |35 x70 x20mm,rotated in plan |
| Perfboard | x=0,y=0 |100 x80 x21.6mm populated |
| PCA9685 | x=70,y=0 |30 x65 x15mm,rotated in plan |

The three printed frames occupy174 x82mm overall. Nominal populated height
above deck is29.6mm. Board edge gaps are2.5mm and5mm; actual headers,USB plugs,
antenna and cable bends must be checked. Move/modify the provisional frames
if these spaces are inadequate. Do not infer connector accessibility from
rectangular reservations. There is no body travel/cable sweep qualification.

Four narrow ties,width<=2.5mm,secure frames through existing paired deck slots:
ESP lane x=-60;perfboard lanes x=-15 and15;PCA lane x=60;all at y=+/-20mm.
The straps cross the printed beams below the boards,not populated board faces.
Thread before closing the chassis. Choose actual tie length for the loop;
about150mm or longer is a starting stock assumption,not a verified purchase.

Up to six additional ties secure the boards (two each),only across confirmed
blank PCB areas or safe insulating adapters. Perfboard ties can use the x=+/-46
underside relief channels. Controller boards may need verified mounting holes
or separate insulating adapters if no blank strap lane exists. Never cinch
across components,USB/headers,solder or antenna. Actual retention remains
untested. Conditional maximum ten ties replaces earlier generic four or stacked
eight electronics-mount ties; leg ties are separate. Reuse suitable stock.

The frames leave sixteen nominal7mm fixing-head paths clear. An assumed4mm
head/washer height fits below the8mm PCB underside. Actual head/washer height
must be checked. Boards cover some screwdriver access:turn power off and lift
removable boards/frames for chassis servicing. This tradeoff reduces hardware,
height and plastic compared with the stacked alternative.

## Validation and mass

Run `node mechanical/check-electronics-sleds.mjs`. Three meshes are closed,
connected and bed-oriented.472 strap/support/fixing/relief checks pass;placed
frame bounds do not overlap and lie inside the deck. Fresh CGAL intersection
with all three board reservations is empty (0.001mm support-face relief).
Preview was rendered and visually inspected. Physical fit/retention is pending.

Combined solid PETG volume corresponds to24.5g,versus79.8g for the two-tier
option:55.3g less solid CAD material and no four M3 bolt/nut/washer sets.
These are comparable CAD volumes,not measured print masses. Slicer/scale values
supersede them. The integrated robot estimate remains2.178kg,above2kg;the
frames are not adopted in its93-piece manifest or mass record. The first-leg
manufacturing pack remains MFG-003. If adopting later,use one electronics
mount option,replace the deck once,and account for all actual print/hardware
masses rather than adding both alternatives.

Current [mass policy](servo-qualified-mass.md):2kg is preferred;heavier is allowed within demonstrated servo/power duty. No physical qualification is recorded.

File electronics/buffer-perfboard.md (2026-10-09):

> Superseded MG996R/PWM design reference. Active design is ST3215 12V with3S power; see README.md,docs/st3215-leg-build.md and electronics/st3215-power-plan.md. These quantities,interfaces and mass estimates are not the current ST3215 design.

# Signal-buffer perfboard carrier — ELEC-006

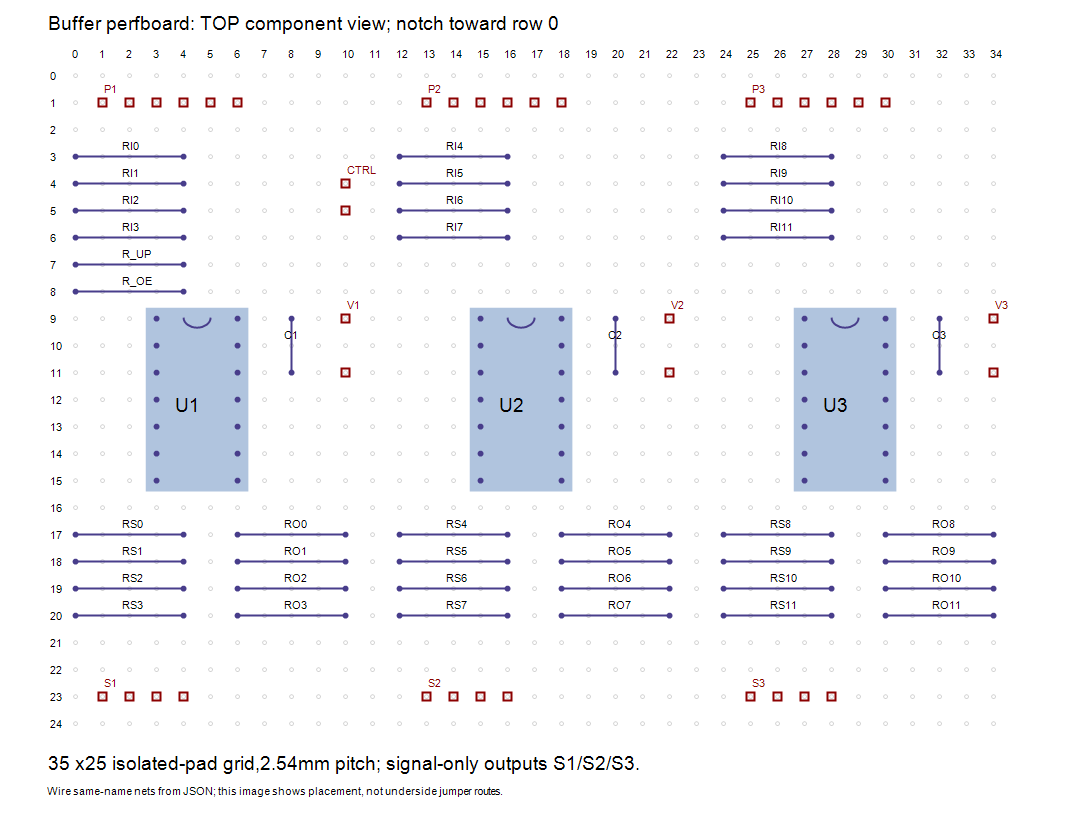
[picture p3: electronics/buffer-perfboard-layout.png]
Top-side placement


Use a nominal100 x80mm isolated-pad perfboard with at least35 x25 usable holes
on2.54mm pitch. This is a provisional hand-wired layout, not a custom PCB or
a verified purchased board. Actual hole grid, socket/component bodies and
mount clearance require a dry fit before soldering. Never use uncut stripboard
for this plan: its copper strips would join unrelated nets.

Top component view: columns increase right, rows increase down. All three DIP
notches point toward row0. Pins1..7 run down the left socket column;14..8 run
down the right. U1 left/right columns3/6, U2 15/18, U3 27/30; rows9..15.
The column separation is7.62mm. Mirror the grid when viewing the solder side;
mark pin1 and an asymmetric board corner before turning it over.

## Placement and connections

| Item | Grid rule, zero-based |
| --- | --- |
| U1/U2/U3 base column |0 /12 /24 |
| Input10k RI0..RI11 | local columns0 to4, rows3..6 by gate |
| Signal220ohm RS0..RS11 | local columns0 to4, rows17..20 by gate |
| Output10k RO0..RO11 | local columns6 to10, rows17..20 by gate |
|100nF C1/C2/C3 | local column8, rows9 and11 |
| Six-pin PCA header P1/P2/P3 | local columns1..6,row1; four input signals,OE,3V3 |
| Four-pin signal header S1/S2/S3 | local columns1..4,row23; signals only |
| Buffer supply V1/V2/V3 | local column10,rows9(+5.2V) and11(GND) |
| Common OE220ohm R_OE | columns0 to4,row8 |
| Common OE1k R_UP | columns0 to4,row7 |
| CTRL GPIO6/GND | column10,rows4/5 |

The JSON lists every terminal and complete net endpoints, including chip pins.
Wire endpoints with the same net name together using insulated point-to-point
wires on the solder side; different net names must never share bare copper.
This gives a connection plan, not guaranteed non-crossing wire routes. Keep
wire runs short and inspect crossings for insulation. Axial resistors span
10.16mm; choose parts that fit or adjust before soldering. Capacitor lead
spacing here is5.08mm; adapt leads without bridging adjacent pads. Each C
is placed beside its chip supply pins; connect to14/7 by the shortest practical
paths. Sockets permit inexpensive chip replacement.

P1 carries PCA0..3,P2 4..7,P3 8..11. S1/S2/S3 carry corresponding buffered
signals. Label each lead with the leg/joint from four-leg-harness.md. Do not
connect servo motor-positive or motor-return wires to these headers. V1..V3
supply only the buffers from the common switched5.2V rail and logic reference
ground; they are not motor distribution connectors. Never join split regulator
outputs through these headers. OE headers form one shared net, not three
GPIO drivers. R_UP pulls OE to logic3.3V, not servo5.2V.

## Build and inspect later

Fit sockets and headers without solder first, mark orientation/labels, then
fit passives and insulated jumpers. Mount on insulating supports with access
to both sides. The electronics deck slots can hold a removable insulating
carrier; actual mounting holes and installed clearance remain TBD. This buffer
board adds an unmeasured100 x80mm space claim and is not incorporated into
the current chassis/mass model. Avoid stacking across USB or antenna access.

Before chips/servos are connected, check every same-net continuity and no
short between3.3V,5.2V and GND. Check each signal independently against the
JSON. Power/verify the original one-servo bench harness first; no12-servo
activation or powered result is claimed. OE level, buffer rail and physical
cutoff behavior must be measured on the assembled board.

Buying delta: one suitable isolated-pad perfboard, three14-pin DIP sockets,
three six-pin signal input headers, three four-pin signal output headers,
three three-position headers with centre pins removed for the two-terminal buffer supplies and one two-terminal CTRL header;
reuse existing resistor/capacitor/buffer totals. No purchased board geometry,
connector rating or retail price is selected. Exact hardware is provisional.
Check:node electronics/check-buffer-perfboard.mjs.

User preference:initial prototypes use perfboard; consider SMT for the final
design after hardware behavior is demonstrated. DigiKey is the preferred
supplier. Final package pinouts/footprints must be checked independently;
the PDIP layout is not a ready-made SMT PCB design.

Provisional compatible parts and reference buying costs: [DigiKey population list](digikey-perfboard-bom.md). PAD2 is the 100 x80mm candidate; retain the logical35 x25 grid. Supply headers use their outer pins at5.08mm spacing.

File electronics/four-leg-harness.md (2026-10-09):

> Superseded MG996R/PWM design reference. Active design is ST3215 12V with3S power; see README.md,docs/st3215-leg-build.md and electronics/st3215-power-plan.md. These quantities,interfaces and mass estimates are not the current ST3215 design.

# Provisional four-leg harness — ELEC-004

This offline wiring plan extends the bench architecture; it does not enable
powered four-leg control. Actual board headers, delivered servo current and
robot supply remain unverified. The one-servo commissioning procedure stays
in bench-wiring.md. MG996R candidates only; direction/angle calibration remains
unset. Rear-leg joint labels do not imply global-forward motion.

```mermaid
flowchart LR
 USB --> ESP[ESP32-S3]
 ESP -->|3.3V logic and I2C| PCA[PCA9685]
 ESP -->|GPIO6 common disable| OE[OE bus]
 OE --> PCA
 OE --> BUF[Three AHCT125 buffers]
 PCA -->|12 signals| BUF
 SUP[Robot servo supply TBD] --> FUSE[Main protection TBD]
 FUSE --> CUT[Accessible DC cutoff]
 CUT --> STAR[Rated external power star]
 STAR -->|four protected leg feeds| LEGS[12 separate servo power branches]
 STAR -->|switched5.2V| BUF
 BUF -->|12 buffered signals| LEGS
```

## Signal connections

ESP32 GPIO4/5 to PCA SDA/SCL, VCC and pull-ups3.3V, address0x40 provisional.
GPIO6 through220ohm to common OE; one1kohm pull-up to logic3.3V. Connect OE
to PCA OE and pins1,4,10,13 on all three buffers. HIGH disables outputs.
Each buffer: pin14 to switched servo rail, pin7 to common ground, one100nF
ceramic at14/7. Orient the PDIP notch before counting pins; other packages
need their own verified pinout. All12 gates are used.

| PCA channel | Leg/joint | Buffer/gate | A input | Y output | OE |
| --- | --- | --- | ---: | ---: | ---: |
| 0 | FL/J1 | U1/1 | 2 | 3 | 1 |
| 1 | FL/J2 | U1/2 | 5 | 6 | 4 |
| 2 | FL/J3 | U1/3 | 9 | 8 | 10 |
| 3 | FR/J1 | U1/4 | 12 | 11 | 13 |
| 4 | FR/J2 | U2/1 | 2 | 3 | 1 |
| 5 | FR/J3 | U2/2 | 5 | 6 | 4 |
| 6 | RL/J1 | U2/3 | 9 | 8 | 10 |
| 7 | RL/J2 | U2/4 | 12 | 11 | 13 |
| 8 | RL/J3 | U3/1 | 2 | 3 | 1 |
| 9 | RR/J1 | U3/2 | 5 | 6 | 4 |
| 10 | RR/J2 | U3/3 | 9 | 8 | 10 |
| 11 | RR/J3 | U3/4 | 12 | 11 | 13 |

Each A input has10kohm to ground. Each Y output goes through220ohm to its
servo signal connector, with10kohm to ground at the connector. Label both ends
FL/FR/RL/RR and J1/J2/J3. Verify actual servo wire polarity; do not rely on
colours. Three chips are the minimum for12 signals; contiguous four-channel
chip groups simplify pin numbering, although they cross leg boundaries.
PCA12–14 stay full-off/unconnected;15 remains the board-only timing loopback.

The [TI datasheet](https://www.ti.com/lit/ds/symlink/sn74ahct125.pdf) supplies
the14-pin gate map, TTL input limits and4.5–5.5V operating range. Our existing
harness limit stays5.3V maximum. [NXP](https://www.nxp.com/docs/en/data-sheet/PCA9685.pdf)
defines16 PWM outputs, common OE and configurable disabled-output states.
PCA MODE2=0x04 and full-off initialization remain required before later arming.
This task changes no firmware. Module OE pulldown conflicts must be checked;
verify OE high with MCU disconnected and every buffer powered before motion.

## Power boundary and purchases

Each servo receives its own positive/ground pair from the external distribution;
no motor current through ESP32, breadboard or PCA V+ tracks. PCA V+ remains unused.
Connect logic and buffer grounds to the star without routing servo return
current through their boards. Switched motor power also supplies the buffers.
The physical cutoff must be accessible outside the moving legs. OE is signal
disable, not power isolation; a servo can retain its last commanded position.

Reuse2A per-servo allowance:6A per leg,24A total;25% capacity margin gives
7.5A per leg and30A total planning capacity. This is a sizing warning, not
a measured requirement or a selected30A supply. The bench5A supply/10A path
is not a released full-robot supply. Robot battery, regulator, main fuse,
main wire and connectors remain TBD; ratings, voltage drop and protection
coordination need checking when actual current and supply are chosen. The
existing18/22AWG bench recipe must not be copied into a24A main feed.

Conditional signal totals:3 AHCT125N,3 x100nF ceramics,13 x220ohm resistors
(12 signal+oneOE),24 x10kohm pulldowns andone1kohm OE pull-up. Relative to
the bench signal harness, add2 buffers,2 capacitors,9 output paths,9 series
resistors and18 pulldowns; share the existing OE resistor/pull-up. These are
totals, not quantities to add twice. Owned controller boards need no replacement.
Use perfboard/sockets for logic; rated distribution handles power. No new
regulator/battery purchase or verified retail price is claimed. Buy/test one
servo before committing to the full harness. Check the3.3V and5.2V domains,
continuity, polarity, OE disabled state and one channel at a time on hardware.

Data:four-leg-harness.json. Check:node electronics/check-four-leg-harness.mjs.
All physical tests remain NOT_PERFORMED; this is a provisional connection plan.

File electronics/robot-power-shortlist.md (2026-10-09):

> Superseded MG996R/PWM design reference. Active design is ST3215 12V with3S power; see README.md,docs/st3215-leg-build.md and electronics/st3215-power-plan.md. These quantities,interfaces and mass estimates are not the current ST3215 design.

# Robot-power feasibility shortlist — ELEC-005

Checked public information2026-10-09. No supplier contact or purchase.
Retain the simple common5.2V servo-rail architecture provisionally and measure
one servo/leg before buying a full-robot supply. The30A allowance is a planning
capacity screen, not measured continuous draw. No shortlisted product is locked.

| Candidate | Quantity and price evidence | Relevant limit | Decision |
| --- | --- | --- | --- |
| Hobbywing30606000 UBEC25A HV | One; US$73.99 collection sale / US$107 product MSRP; shipping/tax extra |5.2V setting,25A continuous/50A peak,9–80V main input,74g | Below30A capacity screen; reconsider only after demand measurement |
| Hobbywing30603000 UBEC10A aircraft | Four isolated outputs; NZ$64.99 each =NZ$259.96 incl listed GST, freight extra; out of stock |5V setting,10A continuous/20A peak each,6–25.2V input,36g each | Electrically plausible7.5A-per-leg screen; too costly/complex to lock and not presently available |
| Pololu2881 D24V150F5 | Two isolated outputs; US$79.95 each =US$159.90 before shipping/tax |5V +/-4%,typical15A each depends on input/thermal conditions | Costly;4.8V low tolerance leaves no lead-drop margin; advertised current needs thermal verification |

Technical sources: [Hobbywing25A](https://www.hobbywingdirect.com/collections/storewide/products/ubec-25a-hv),
[Hobbywing aircraft10A](https://www.hobbywing.com/en/products/ubec-10a-2-6s152),
[Pololu2881](https://www.pololu.com/product/2881). Price/availability:
[Hobbywing collection](https://www.hobbywingdirect.com/collections/ubec) and
[RC Hobbies NZ](https://www.rchobbies.co.nz/hobbywing-30603000-10amp-ubec-2-6s/).
Prices are a dated comparison, not a quotation or a currency conversion.

Do not confuse30603000 with30603003: the latter is the10A-Car product with
6/7.4/8.4V outputs and does not fit the current5.3V buffer rail maximum.
[Current regional product](https://www.hobbywingdirect.com/products/ubec-10a).
Peak current cannot substitute for continuous capacity. Two15A outputs or
four10A outputs supply separate groups; they must not be joined in parallel.

A split-output alternative would require a revised signal-buffer power map:
the current three-chip plan crosses leg boundaries. Power each buffer/output
only from the associated servo domain and define disabled behavior for a missing
rail before adopting that architecture. Do not connect separately regulated
positive outputs through buffer VCC wiring. Grounds may be common as required
by control; load returns still belong at each distribution point.

The four-BEC price alone consumes26–52% of theNZ$500–1000 project range.
PROJECT.md's approximately10% repeated-component threshold requires explicit
approval before locking such a selection. No approval is needed to retain
this unselected comparison. A single25A unit is simpler, but buying it now
would silently discard the existing capacity margin. Neither is justified yet.

Main protection/cutoff, battery input wiring and post-regulator servo wiring
need actual ratings and voltage-drop checks with the chosen supply. A switch
on a BEC is not automatically rated power isolation. Battery protection,
polarity, regulator transient behavior and buffer rail voltage remain untested.
Do not copy the18AWG bench main path into a24A servo bus. Split supplies remove
a common high-current5V positive bus but add branches, regulators and fault cases.

Next power decision needs measured startup/loaded current and minimum servo
voltage for one real leg, actual regulator thermal behavior, landed price and
mass. Keep the battery/regulator/fuse/wire/connector fields TBD. The2kg mass
record remains unmeasured; regulator mass is part of its existing allowance,
not an extra mass to add twice. No new BOM purchase is released.

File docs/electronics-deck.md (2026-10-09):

# Universal electronics attachment deck — MEC-166

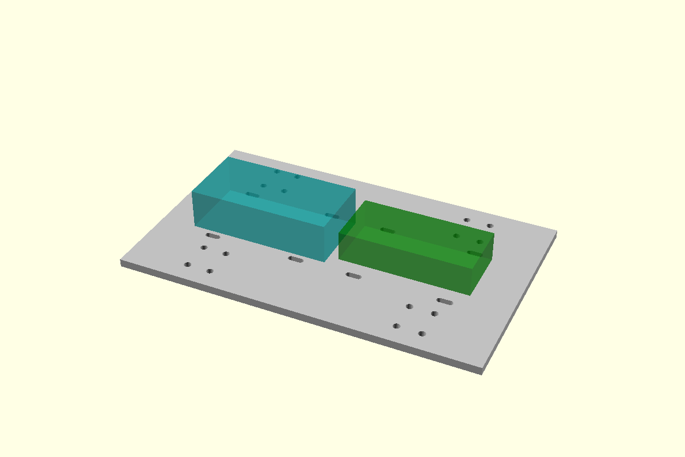
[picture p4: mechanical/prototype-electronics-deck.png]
Layout reservations


Working option: mechanical/prototype-electronics-deck.scad and its STL.
It replaces the original chassis deck, retaining180 x110 x4mm and the16 M3
chassis fixings. Eight8 x3mm through-slots form four strap lanes at x=-60,-15,
15,60mm and y=+/-20mm. The single-leg MFG-003 kit is unchanged.

Use four narrow cable ties, nominal width2.5mm or less, one per paired lane.
Reuse an existing tie pack. The slots attach removable insulating carriers or
mounts; they are not mounting holes for a guessed PCB. Do not cinch a tie over
components, exposed solder joints, connectors or the ESP32 antenna. Keep bare
PCB undersides clear of the deck using suitable insulating supports; the3mm
space shown below each reservation is only a starting layout allowance.
Supports and actual connector/cable access must be checked against your boards.
No PCB hole pattern, direct-board fit or completed mount is claimed.

The teal70 x35 x20mm and green65 x30 x15mm blocks reuse the existing unmeasured
ESP32/PCA9685 space claims. Keep USB, headers and the physical servo-power
cutoff accessible. High-current wiring still uses the separate rated power
star; the PCA board and deck slots are not servo-current distribution parts.
No battery, regulator or electrical component is selected by this task.

Print flat as exported. Use the same conservative PLA+/PETG process as other
prototype plates and inspect small slot layers. The deck itself adds no raised
geometry or support requirement. Check tie passage and fixing washer clearance
on a print before fitting electronics. Fit/load remains NOT_PERFORMED.

Check: node mechanical/check-electronics-deck.mjs. The actual STL is closed,
connected and bed-sized;169 mesh rays test slots, side walls, retained fixings
and central material. Minimum slot-to-fixing ligament is6.75mm. Volume removal
matches eight slots. The variant only removes material from the old deck, so
it adds no geometry to the previously screened nominal deck/leg clearance.
This does not qualify electronics clearance, stiffness or loaded operation.

The option is not yet substituted into the93-piece four-leg plan or mass record.
Use one deck, not both, if later adopting it. Manufacturing stays at MFG-003
until a requested build checkpoint includes this chassis option.

MEC-167 now provides an optional two-tier printed carrier:
[electronics carrier](electronics-carrier.md). Its specific strap plan replaces
the generic four-tie allowance when adopted. Actual board fit/mass remain
pending; no manufacturing or robot-manifest substitution.

Preferred working attachment is now [three single-level sleds](electronics-sleds.md)
using all four existing strap lanes. It replaces the stacked carrier when
nominal single-level board/connector fit proves acceptable on actual hardware.

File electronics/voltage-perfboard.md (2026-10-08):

# Removable perfboard voltage input — ELEC-008

This optional input prepares voltage measurements using the owned ESP32-S3,
multimeter and adjustable supply. It is a **manual bench diagnostic**, not an
always-connected battery monitor or battery protection system. No battery is
selected. Positive test voltage is limited to0..25.2V; never connect60V or a
negative voltage. The voltage source must not be wired to the servo rail while
performing this diagnostic; keep servo power OFF and disconnect all servos.

## Circuit and perfboard placement

```text
VS_IN + -- RV_TOP 150k --+-- VS_ADC signal --> GPIO8 (ADC1_CH7)
                        |
                        +-- RV_BOTTOM 10k -- GND
                        |
                        +-- CV 100nF ------- GND
VS_IN GND --------------+-- VS_ADC GND ----- ESP32 GND
```

Both resistors are axial5%,1/8W; CV is the same50V X7R100nF radial part as
buffer decoupling. Connect all same-name nets using insulated jumpers. The
source/input terminal must connect only through RV_TOP to ADC8. This is a
sense-current branch, not a motor-power branch. Check GND continuity first.

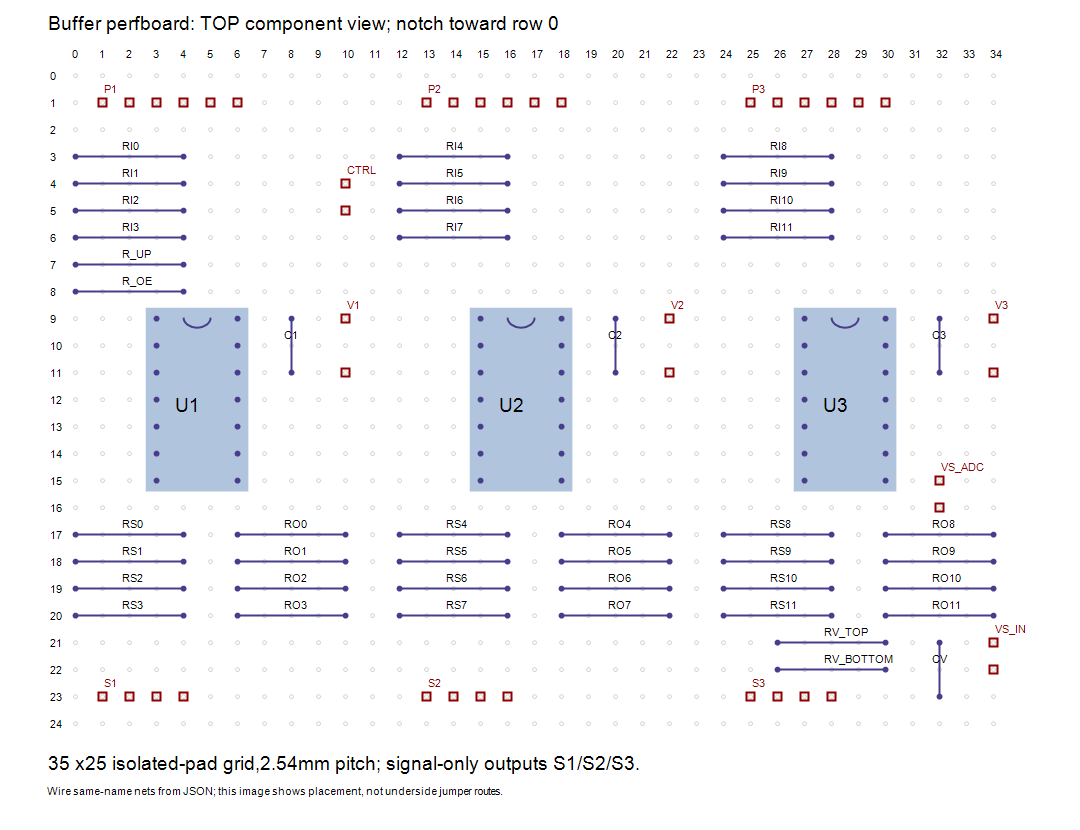
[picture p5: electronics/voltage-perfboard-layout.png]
Optional voltage input positions


The optional addon fits unused positions in the existing35 x25 logical grid;
its file is voltage-perfboard-addon.json. Top view, zero-based coordinates:

| Item | Pads and net order |
| --- | --- |
| RV_TOP150k | columns26/30,row21; SENSE_POS/ADC8 |
| RV_BOTTOM10k | columns26/30,row22; ADC8/GND |
| CV100nF | column32,rows21/23; ADC8/GND |
| VS_IN2-pin header | column34,rows21/22; SENSE_POS/GND |
| VS_ADC2-pin header | column32,rows15/16; ADC8/GND |

The checker finds172 unique pads including the original162; no original nets
or components move. The resistor lead span is10.16mm, cap spacing5.08mm.
Actual socket/header bodies, solder crossings and mounting remain dry-fit
checks. These headers are unkeyed: mark +,GND and ADC8 before connecting.
Do not confuse the sense-input connector with the5.2V buffer supply connector.
Verify actual ESP32 board GPIO8 location and that it is unused before wiring.
[Espressif GPIO mapping](https://docs.espressif.com/projects/esp-idf/en/release-v5.3/esp32s3/api-reference/peripherals/gpio.html)
identifies GPIO8 as ADC1_CH7; GPIO4..7 remain assigned to I2C/OE/timing.

## Minimum electrical checks

Nominal divider is16:1:5.2V gives325mV at ADC8;25.2V gives1.575V.
Worst5% resistor combination gives1.7294V at25.2V. This remains below a
conservative2.0V diagnostic ceiling and the published older2.5V ADC range
at11dB attenuation. Conservative resistor powers are under4.34mW/0.30mW,
well below125mW ratings. Equivalent source resistance9.375k with100nF gives
0.938ms RC; the diagnostic waits5ms then takes16 pairs with1ms waits.
[Espressif ADC guidance](https://docs.espressif.com/projects/esp-idf/en/v4.4.7/esp32s3/api-reference/peripherals/adc.html)
and [hardware filter recommendation](https://documentation.espressif.com/projects/esp-hardware-design-guidelines/en/latest/esp32s3/schematic-checklist.html).

This divider is not precision-calibrated:5% individual resistors can cause
roughly10% scale error, and ADC error adds to it. Compare against the multimeter
before using readings for any decision. Firmware reports an estimate using
nominal16:1 scaling. ADC software limits do not physically protect an input.
A missing ground, incorrect resistor or excessive voltage can still damage it.

## Power sequencing and later comparison

1. Leave the sense positive disconnected and servo power OFF. With ESP32
   disconnected, inspect polarity, continuity and resistor values. Connect
   supply negative to circuit GND; set a low current limit suitable for this
   tiny circuit. Independently check the divider output with the multimeter
   at a modest input voltage before ever plugging it into GPIO8.
2. Turn the test source OFF/disconnect its positive. Connect verified GPIO8/GND
   and power the ESP32 from USB first. PCA logic must be connected as in the
   existing bench harness so the controller can initialize DISARMED. Connect
   the sense positive last, then enable only the separate test source.
3. From a manual serial terminal at115200 baud, while DISARMED, enter exactly
   `voltage rail-off no-servos`. The existing supervised console does not yet
   expose this command. Operator words acknowledge setup; they are not voltage
   measurements. Firmware reasserts OE high/full-off and never enables outputs.
4. Compare source voltage and ADC-node voltage measured by the multimeter with
   `input_mv` and `adc_mv`. Start around5.2V, then optionally12V and25.2V on
   the **sense circuit only**, after confirming wiring. Record actual readings
   and spread; no such readings have been made yet. Do not infer accuracy from
   an example output or synthetic host test.
5. Turn OFF/disconnect sense positive **before** removing ESP32 USB power;
   wait at least10ms for the filter to discharge. Never leave this input
   connected to a live battery while ESP32 is unpowered. No powered-off
   isolation/clamp is provided by this manual prototype. An always-connected
   onboard implementation needs a separately checked isolation arrangement.

Response fields: result,adc_mv,input_mv,spread_mv,raw,samples,calibrated=false.
`READING` means a complete software acquisition, not physical accuracy approval.
`LOW_OR_DISCONNECTED` can mean low input, an open lead or ADC calibration failure;
never interpret it as a confirmed dead battery. A raw4095 or ADC value above
2000mV rejects the acquisition. A read failure/partial acquisition yields no
input estimate. Raw and calibrated values are successive conversions, not
identical simultaneous samples. No battery chemistry/cutoff threshold is set.
An armed request latches the existing command fault and disables outputs;
a faulted request cannot recover the controller. It does not extend keepalive.

## Buying delta and validation

Optional delta: one150k axial resistor (CF18JT150K candidate; DigiKey preferred,
[public listing](https://www.digikey.co.nz/en/products/detail/stackpole-electronics-inc/CF18JT150K/1741592)),
one10k CF18JT10K0 and one C322C104K5R5TA100nF. Reuse the spare10k from the
25-pack and cut two2-pin headers from the spare positions in the two40-pin
strips. Reuse suitable existing wire/board/components. Otherwise budget roughly
NZ$2–3 for the small passive delta, subject to checkout prices and shipping;
this is an estimate, not an additional verified quotation. The original
DigiKey buffer subtotal stays32.82 and does not include this optional addon.

Independent check:`node electronics/check-voltage-perfboard.mjs`.
Firmware:`firmware/test.ps1` and `firmware/build.ps1` using existing local tools.
No firmware upload, electrical measurements or automatic battery cutoff occurs.

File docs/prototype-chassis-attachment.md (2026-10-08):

# Removable chassis attachment — MEC-156

Working CAD: `mechanical/prototype-chassis-assembly.scad` and
`mechanical/prototype-chassis-mount.scad`. These are development outputs;
MFG-002 remains the single supported bench-leg release.

## Print and assemble

Print two `prototype-chassis-mount-left.stl`, two
`prototype-chassis-mount-right.stl`, and one `prototype-chassis-deck.stl`.
The mounts export flat on their large mounting plate,66 x59mm and33mm tall;
the deck exports flat,180 x110 x4mm. Start with PETG or PLA+,0.2mm layers,
four walls and ordinary prototype infill; inspect the slicer preview. No
support is intended for the mounts in the exported orientation. Actual print
fit and strength remain untested.

The left print serves front-left and rear-right; rotate180deg about body z
for the rear-right. The right print serves front-right and rear-left, again
rotating180deg for the rear-left. Handed leg components remain a separate
working plan in docs/four-leg-working-assembly.md; these brackets alone do not
make a four-leg build kit. MEC-158 corrects the mount print-to-world rotation;
use current left/right STLs, which retain dimensions and fixing patterns.

Replace the bench adapter with the bracket's7mm mounting plate. Its contact
face sits at bench-frame x=-3mm, against the existing passive support base.
Four slotted3.5mm holes match y=-3.65/+24.35mm and z=+/-17.25mm. Reuse the
four M3 x20 cradle/support/adapter bolts for each leg; do not stack the bench
adapter behind the bracket. The22mm centre opening retains pivot access.

The6mm upper flange contacts the deck underside35mm above the J1 datum,
which keeps the existing155mm deck height. Each flange takes four M3 x16
through bolts, four nuts and eight ordinary washers. The deck has16 matching
holes. Assemble the fixed mount/support before installing the moving fork
if tool access is restricted. Remove motor power before assembly or service.

Nominal stacks excluding bolt head: reused joint mount3+3+7mm plus washers
and nut; deck joint6+4mm plus washers and nut. Verify actual nut/washer
thickness, thread engagement and protruding tips before tightening. Do not
let clamp torque crush the print or servo case. Servo cable relief remains
at the existing end of the cradle; actual leads/horns require physical checks.

## Validation and limits

`node mechanical/check-chassis-mount.mjs` reads all three working STLs.
It checks closed edges, connected surfaces, bed origin, dimensions, equal
mirror volumes and mesh-ray clearance through fixing holes on a3mm envelope.
Bounds remain inside a conservative300mm print area, without relying on an
unverified printer profile. The assembly preview is inspected separately.

Full nominal mount/leg intersection is checked with OpenSCAD mode
`mount-leg-collision`. The corrected nominal intersection is empty. Moving
travel, cables, real servo ears and wrench clearance remain physical prototype checks.
The printed bracket/deck mating face is intentional contact.
The initial bracket interfered with the passive-support ribs;0.2mm clearance
pockets now follow those existing ribs. The collision mode excludes only a
0.001mm layer at the intended support contact face.

Solid PETG estimates:31.5g per bracket and99.8g deck; four brackets plus deck
approximately225.9g. These are solid CAD volumes, not sliced or measured mass.
Keep the complete2kg limit and measure the actual assembly before choosing
robot power/battery hardware. No detailed structural optimization is warranted
until a supported physical trial identifies a problem.

Board blocks remain conservative unmeasured reservations for the owned ESP32
and PCA9685. Their attachment holes are not guessed. No battery mount, gait,
powered standing or manufacturing release is included.

The same rib check exposed127.65mm3 of interference with the older bench
adapter, corrected by MEC-157. Bench-3 also corrects carrier/saddle handed-print
selection; use the current kit. Fit coupons remain useful.

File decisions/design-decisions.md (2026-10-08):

# Design decisions

## MFG-001 — Manufacturing release scope, 2026-10-08

Adopt manufacturing/ as the current release-output location, following the new
AGENTS.md rules. Package the existing pitch-leg-1 mechanical design without
changing geometry: 16 assembly STLs/20 pieces and four fit coupons, current
hardware BOM, self-contained assembly instructions, STL-derived dimensions,
assembly image and editable transitive SCAD source snapshot.
Fresh exports and independent mesh/package checks verify consistency. This is
a release for printing and unpowered fit assessment, not a complete robot or
powered release. Physical fit remains untested. STEP and electrical/firmware
outputs are absent because those designs/workflows have not been released.
Future manufacturing changes must update affected outputs and manifest;
obsolete releases move to ARCHIVE rather than remain in manufacturing/.
No new dependency, purchase, architecture change or engineering stage advance.

## ARCH-001 — Requirements and leg topology, 2026-10-07

Status: adopted as an architecture baseline; physical feasibility unvalidated.

Decision: use four serial three-DOF legs, each ordered hip abduction/adduction,
hip pitch, knee pitch, attached to a common chassis. Initially assume one
servo per joint and a passive foot contact, for twelve actuators total.

Reason: this topology directly represents the user's requested motions and
provides a bounded starting point for a reference-leg kinematic model.

Preserve the user's approximately 180 x 110 mm body, total operating mass
below 1.2 kg, FDM construction, provisional 70/85 mm link lengths, and
MG90S-sized metal-gear servo candidate. None of these provisional dimensions
or actuator capabilities has been validated. Existing ESP32-S3 and PCA9685
entries remain deferred assumptions only.

Downstream implications: the reference-leg task must define axis directions,
origins, and mirror conventions. Later pose/workspace and torque tasks must
test this baseline before detailed mechanical design. Actuator changes may
require revisiting packaging, offsets, and mass allocation.

Source: user brief, AGENTS.md, and initial STATUS.md. PROJECT.md records the
complete baseline and distinguishes requirements from assumptions. Earlier
conversational geometry/torque exploration is not an approved design result.

## KIN-001 - Reference-leg frames and axes, 2026-10-07

Status: adopted mathematical convention; eight offline geometry checks pass.

Decision: use right-handed body and fixed leg-root frames with +x forward,
+y left, and +z up. Define symmetric roots as (f*a, s*b, h), with front/rear
sign f and left/right sign s. Positive abduction is outward, hip pitch is
forward from vertical-down, and knee flexion bends the lower link backward
relative to the upper link. Zero angles mean a straight downward reference
leg, not a selected standing pose.

The abduction signed axis is s*x. Hip pitch is about the abducted -y axis;
knee flexion is about the abducted +y axis. The J1-to-J2 offset is (u,s*d,w)
before abduction. All dimensions remain parameters; the subsequent ideal
links have no additional lateral offset. Axis reference centres and signed
directions are defined fully in docs/leg-frames.md.

Left/right skeletons are reflections, but their coordinate frames remain
right-handed. Rear legs translate the front-leg geometry rearward and use
the same joint conventions; they are not fore/aft-reflected mechanisms.

Reason: consistent geometric angles across all legs allow shared equations
and avoid left-handed right-leg frames. Explicit offset parameters preserve
packaging freedom without hiding axis-location assumptions.

Validation: mechanical/check_leg_frames.py checks handedness, zero geometry,
motion signs, axis/link invariants, left/right reflection, front/rear
translation, independent scalar equations, and finite-difference joint
motion against axis cross lever-arm geometry. Eight tests pass, using 43
deterministic angle samples per leg where sampling applies. Fixture values
are verification inputs, not approved dimensions or ranges.

Downstream implications: the numeric skeleton must use these signs and
offset definitions. Additional lateral link offsets or fore/aft-reflected
knee arrangements would require revising this contract and its checks.
Servo command polarity remains a later calibration issue. No torque,
workspace, packaging clearance, or physical feasibility is established here.

## KIN-002 - Candidate numeric skeleton, 2026-10-07

Status: adopted candidate for further kinematic analysis; physical feasibility
unverified. Seven candidate/drawing checks and all eight KIN-001 checks pass.

Decision: a = 75, b = 55, h = 0, u = 0, d = 25, w = 0, Lu = 70, Ll = 85 mm.
Preserve the 180 x 110 mm chassis planform. Place the body datum on the common
J1 plane; chassis top, bottom, and thickness remain undefined. This instantiates
KIN-001's parameters without changing its frames, angles, or leg mapping.

Reason: 150 mm longitudinal root spacing leaves a 15 mm nominal end inset;
placing roots at the chassis side boundaries makes the initial layout easy
to reference. A 25 mm outward pitch-centre offset is a compact starting
allocation, not a measured servo packaging result. Zero longitudinal and
vertical hip offsets simplify the initial skeleton. The link centre lengths
retain the user's 70/85 mm targets.

Derived zero-reference geometry: J1 roots form a 150 x 110 mm rectangle;
pitch-leg planes are 160 mm apart; straight hip-to-foot distance is 155 mm.
The zero-angle drawing is singular in the pitch plane and is not a stance.
With u = w = 0, J1/J2 infinite axes intersect: the 25 mm dimension locates
reference centres along J2 and is not an axis-to-axis minimum distance.

Validation: mechanical/check_leg_skeleton.py compares JSON coordinates with
the KIN-001 matrix chain; checks body insets, outboard distances, centre
lengths, reflection and rear translation; and checks SVG markers, link
projections, dimension-line lengths/labels, and documented coordinates.
The existing frame checker also passes unchanged. These are mathematical
and document checks, not physical fit, load, or printability validation.

Downstream implications: use this candidate for a nominal-standing-pose
task. Later actuator packaging or torque results may require changing hip
offsets, link lengths, or root locations. Any such revision must update the
JSON, drawing, documentation, checks, and this decision record. No servo
adequacy, joint limits, workspace, or detailed mechanical design is approved.

## KIN-003 - Nominal standing-pose candidate, 2026-10-07

Status: adopted geometric pose candidate; physical supportability unverified.
Eight new pose checks and all fifteen previous geometry checks pass.

Decision: keep the KIN-002 skeleton unchanged and place the level body datum
120 mm above ideal ground, with zero abduction and feet directly below H.
Every leg uses q1 = 0, q2 = 44.048625674, q3 = 78.978550364 degrees under
KIN-001. Use the forward-knee branch for both front and rear legs.

Reason: this gives a simple symmetric four-foot pose with bent knees and
no fore/aft foot displacement from the hip-pitch centres. The 120 mm height
is an initial moderate crouch, not an optimized clearance, torque, or
stability result. It avoids the straight-reference pitch singularity.

Derived geometry: feet at (+/-75,+/-80,-120) mm form a 150 x 160 mm contact
rectangle. Relative to H, K is (48.668802572,0,-50.3125) mm. Knees are
69.6875 mm above ideal ground. The front knee centres extend 33.668803 mm
beyond the nominal body front. Body thickness and physical clearances are
still undefined; the 120 mm dimension measures the hip datum, not the underside.

Validation: independent triangle-intersection geometry agrees with the
KIN-001 forward chain; checked geometric angles, link lengths, all-leg mapping,
ground-frame transformation, foot coplanarity, pitch nonsingularity, SVG
geometry/dimensions, and documented coordinates. The combined suite passes
23 tests. SVG was checked as XML/numeric geometry, not raster-rendered.

Downstream implications: candidate angle ranges should include this pose;
later workspace and torque tasks should use it as a reference. Servo mounting,
available travel, interference, holding torque, and COM/stability require
separate validation. Equal foot loads are not assumed or established.
Pose data and derivation are in mechanical/standing-pose.json and
docs/standing-pose.md; the KIN-002 zero-reference drawing is retained.

## KIN-004 - Candidate geometric joint-angle ranges, 2026-10-07

Status: adopted desired ranges for subsequent geometric analysis; measured
hardware limits and simultaneous physical feasibility remain unverified.

Decision: use q1 = [-25,30], q2 = [-40,85], q3 = [20,130] degrees for every
leg under KIN-001. Keep KIN-002 dimensions and KIN-003 nominal angles unchanged.
Closed endpoints define an analysis input only, not operational limits.

Reason: provide moderate inward/outward articulation, allow backward and
larger forward upper-link rotation around the nominal pose, and retain
positive knee flexion away from straight/folded pitch-chain references.
The bounds are engineering starting assumptions, not optimized gait or
clearance results. Spans of 55/125/110 degrees are desired joint travel,
not attributed MG90S specifications.

Nominal reserves to lower/upper boundaries are 25/30 degrees for q1,
84.048626/40.951374 for q2, and 58.978550/51.021450 for q3. These reserves
are arithmetic differences, not established operating safety margins.

Mapping: coordinate rotations are (s*q1,-q2,q3), giving +x abduction intervals
[-25,30] on left legs and [-30,25] on right legs. Local +y hip rotation is
[-85,40] and relative knee rotation is [20,130] on all legs. Rear legs retain
front-leg conventions. These coordinate rotations do not specify servo commands.

Validation: six new checks pass for finite ordered bounds, nominal containment,
spans/reserves, all-leg signed endpoint mapping, frame reflection at eight
angle-box corners plus nominal pose, excluded straight/folded knee references,
and documentation agreement. The complete suite passes 29 tests. No foot
positions or workspace were calculated in this task.

Downstream implications: workspace analysis should use these ranges as a
candidate geometric domain, not assume every angle combination is physically
feasible. Later actuator travel, coupled collision, ground-contact, and load
checks may require narrowing or revising them. No full three-axis singularity,
servo adequacy, stability, or mechanical stop approval follows from this task.
Sources: docs/joint-ranges.md and mechanical/joint-ranges.json.

## KIN-005 - Ideal geometric foot workspace, 2026-10-07

Status: ideal workspace characterized; usable physical workspace unverified.
Seven new workspace checks and the full 36-test geometry suite pass.

Decision: preserve the KIN-002 skeleton, KIN-003 pose, and KIN-004 angle box.
Record continuous marginal bounds relative to the FL J1 root O as
x = [-129.995,146.770], y = [-41.862,97.984], z = [-154.701,38.555] mm.
The nominal root-relative point remains (0,25,-120) mm. These are enclosing
bounds of unfiltered mathematical reach, not an approved Cartesian region.

Method: enumerate planar pitch extrema at corners, edge stationary points,
and interior stationary points; then use affine dependence on planar Z to
reduce y/z extrema to abduction endpoints and stationary angles. Store
attaining joint angles for every coordinate bound. Visualize 103,936 samples
from an endpoint-inclusive 2-degree grid in 2 mm projected occupancy cells.
Distinguish sampled projections from slices and exact reachable boundaries.

Reason: sampled limits alone can miss true extrema; reporting witnesses and
the continuous method makes the approximate workspace independently checkable.
The enclosing box demonstrably includes unreachable points: the root lies
inside the box but outside the necessary radius shell [71.420077,154.700815] mm.

Validation: compare extrema witnesses and random all-leg samples with the
KIN-001 matrix chain, verify a 783,216-point 1-degree grid lies within bounds,
check the independent radius identity, reproduce JSON/SVG outputs, verify
source hashes, nominal/ground plot locations, and documentation agreement.
SVG geometry was checked as XML; no raster rendering/text-layout check was made.

Downstream implications: at nominal body height the unfiltered set includes
points below ground and above the hip plane. Body/link collision, actual
actuator travel, load capability, and stability still require separate checks.
The bounds must not become walking command limits. Proceed next to a bounded
nominal static joint-torque/initial-servo assessment before detailed parts.
Artifacts: docs/foot-workspace.md, mechanical/foot_workspace.py,
mechanical/foot-workspace.json, and mechanical/foot-workspace.svg.

## TOR-001 - Nominal static torque and MG90S assessment, 2026-10-07

Status: nominal contact-load assessment complete; MG90S direct drive is not
approved at the 1.2 kg design ceiling. No replacement or voltage selected.

Assumptions: unchanged KIN-003 pose, 1.2 kg ceiling, gravity 9.80665 m/s^2,
vertical upward foot reactions with per-leg weight shares 1/4, 1/3, and 1/2,
massless moving links, and ideal 1:1 drive. Equal three-foot sharing is only
a hypothetical case requiring its matching COM projection. A half-weight
share is a redistribution screen, not a stable two-leg gait claim.

Results: abduction magnitudes 0.073550/0.098067/0.147100 Nm and knee magnitudes
0.143183/0.190911/0.286367 Nm for those shares. Hip-pitch contact torque is
zero at this exact vertical-under-hip foot location; gravity on moving
components and nonvertical forces are not included.

Source comparison: Tower Pro Hong Kong's MG90S page lists 1.8 kgf.cm at 4.8 V
and 2.2 kgf.cm at 6.6 V; the Tower Pro branded sheet hosted by Electronilab
lists the latter at 6.0 V. Keep this discrepancy explicit and make no supply
choice. Use 0.1765197 Nm as the shared 4.8 V stall reference and 0.2157463 Nm
only as an optimistic published stall comparison. No supported continuous
holding rating was found in those sources. URLs are preserved in the report
and mechanical/static-torque-inputs.json, checked 2026-10-07.

Decision: do not approve the initial MG90S direct-drive baseline at the ceiling.
The half-weight knee case exceeds both stall figures; the equal-four-foot
case being below stall does not establish sustained holding capability.
This is a scoped screening conclusion, not proof about every possible mass
distribution or every servo of similar size. Missing moving-link gravity can
increase or reduce individual moments and must not be labelled uniformly
conservative. Do not invent favourable cancellation or continuous ratings.

Validation: seven new checks and the full 43-test suite pass. Checks cover
independent triangle lever arms, SI/kgf.cm conversion, all-leg signed moments,
finite-difference virtual work, example load equilibrium, source discrepancy,
comparison arithmetic, source freshness, and documented tables. A displayed
rounding discrepancy was corrected before the full suite passed.

Downstream implications: keep the skeleton, pose, and ranges unchanged as
analysis references; retain MG90S as historical packaging only. Resolve an
actuator performance-requirements brief next, including missing duty and
mass-distribution evidence. Do not begin detailed servo brackets or select
a replacement in this task. Dynamic/workspace-wide loads remain open.
Artifacts: docs/static-servo-torque.md, mechanical/static-torque-inputs.json,
mechanical/static_torque.py, and mechanical/static-torque.json.

## TOR-002 - Actuator performance-requirements brief, 2026-10-08

Status: requirements/evidence brief complete; actuator sizing approval open.

Decision: retain TOR-001's three nominal contact-load cases as benchmarks,
not complete continuous or peak requirements. Do not assign the half-weight
case a transient duration or infer continuous capability from stall torque.
Require explicit load uncertainty, duty, speed, thermal and terminal-voltage
evidence before performance approval. No arbitrary torque multiplier chosen.

Reason: moving mass can change both magnitude and sign, while sustainable
support and repeated motion depend on conditions absent from a stall rating.
Zero nominal hip-pitch contact torque does not imply zero actuator demand.

The brief defines nine traceable evidence requirements, mass accounting,
constant-ratio motoring torque/speed/travel relationships and their static
limitations, and staged approval gates. All open inputs have closure methods.
No actuator, transmission ratio, voltage, mass allocation, or geometry changed.

Downstream implications: build the component mass/COM accounting model next;
later candidate evaluation must revisit total mass and distal gravity with
actual placement. Thermal/duty and full operating loads remain open. Detailed
single-leg mechanical design is not released by this document-only task.
Artifact: docs/actuator-requirements.md. Validation is recorded in STATUS.md.

## TOR-003 - Component mass/COM accounting, 2026-10-08

Status: accounting model validated with synthetic fixtures; actual inventory
and gravity loads unresolved.

Decision: count distinct physical instances/groups once across the whole
robot. Assign gravity influence by rigid attachment: body affects no leg
joint, hip carrier q1, upper q1/q2, and lower q1/q2/q3. An actuator's driven
joint label does not select its body attachment. Local COMs use existing
right-handed frames, explicitly mirrored local y on symmetric right parts.

Reason: torque depends on what moves with each joint, while total mass must
also include body-fixed equipment. Adding distal gravity moments does not
add their weight to the contact-force mass a second time.

Unknown mass, COM or attachment withholds affected moments; incomplete
inventory coverage withholds all total gravity corrections and total mass.
The mass-target comparison is strictly below 1.2 kg. No actual mass,
placement, geometry, actuator, transmission or operating limit is selected.

Validation: eight new checks and all 51 mechanical tests pass, including
independent lever-arm and potential-energy-gradient tests on all four legs,
mass accounting, symmetry, invalid inputs and unknown propagation. Synthetic
test masses and offsets are not component estimates or design allocations.

Downstream implications: audit disjoint inventory coverage, split aggregates
by rigid attachment and collect evidence before entering real values. Contact
load sharing must be rechecked against actual COM before combining corrections
with TOR-001. Next collect a bounded candidate actuator evidence table; do
not release detailed mechanical design from this accounting result.
Artifacts: mechanical/mass-inventory.json, mechanical/mass_accounting.py,
mechanical/check_mass_accounting.py and docs/mass-accounting.md.

## TOR-004 - Candidate actuator evidence comparison, 2026-10-08

Status: bounded three-candidate comparison complete; no actuator selected.

Decision: record HS-5085MG, XL330-M288-T and XC330-M288-T as evidence examples,
not an approved shortlist. Their comparison-voltage stall figures exceed the
TOR-001 half-weight nominal knee contact benchmark; none has established
sustained support under project conditions. Preserve all geometry and the
unmeasured TOR-003 inventory.

Reason: mass, travel, interface and published torque can narrow questions,
but cannot replace complete loads and matching thermal/duty evidence. Hitec
default travel is short of the candidate hip span and its voltage limits
conflict across manufacturer sources. Bus candidates imply a later control
interface review; no electronics architecture change is made now.

Validation: primary sources opened and dated; independently checked torque
unit conversion, twelve-unit mass, strict residual mass and nominal ratios.
Published masses exclude unresolved installed hardware accounting and COMs.
No test data or sustained ratings invented; no hardware validation performed.

Downstream implications: define the nominal-standing duty/thermal test
requirements next, with proposed operating targets and unresolved manufacturer
limits separated. Do not release mechanical CAD or select an actuator from
this stall comparison. Artifact: ARCHIVE/2026-10-08-superseded-design/docs/actuator-candidates.md.

## TOR-005 - Provisional standing-duty test requirements, 2026-10-08

Status: test requirements complete; hardware execution not released.

Decision: use three separately cooled 600 s nominal-angle holds at 25 +/-2
degC ambient as a provisional finite standing screen. Target <=2-degree
joint-output tracking error and +/-5% applied nonzero torque tolerance,
including measurement uncertainty. Record fast channels at >=50 Hz and
temperatures at >=1 Hz, with explicit gap limits and independent protection.

Reason: a bounded indoor ten-minute scenario makes sustained-use evidence
questions concrete without claiming indefinite operation. Repeated cooled
starts assess repeatability, not a continuous thirty-minute session. All
numeric targets are engineering proposals; none is a manufacturer rating.

No load torque or protective temperature/current/voltage threshold is invented.
Those require specific evidence, calibrated fixture behavior and completed
load accounting before execution. Ambient limits do not become case/winding
limits. No actuator, geometry, supply or operating capability is approved.

Validation: reference/link and numeric consistency checks passed; reviewed
uncertainty rules, stop conditions and scoped pass/fail/inconclusive outcomes.
No hardware or thermal measurements performed.

Downstream implications: resolve candidate sensor-specific thermal/current
evidence next. Longer/warm-start operation, dynamics and whole-robot support
need separate validation even after a future scoped pass.
Artifact: docs/standing-duty-test.md.
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

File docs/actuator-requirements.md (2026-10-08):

# TOR-002: actuator performance-requirements brief

Date: 2026-10-08. Stage: servo torque validation.

This brief defines the evidence needed to size actuators. It does not approve
an actuator, transmission, voltage, or final torque rating. TOR-001 remains
the nominal contact-load benchmark; sustainable support is unresolved.

## Fixed references and known benchmarks
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

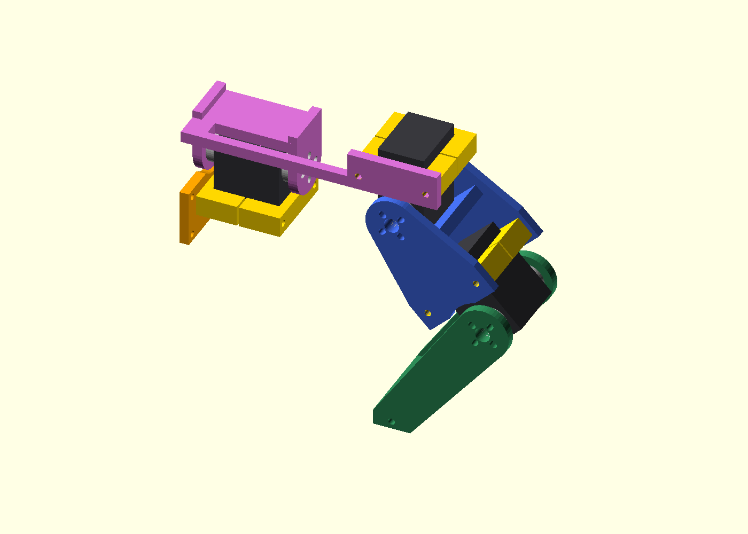
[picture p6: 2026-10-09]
mechanical/st3215-leg.png

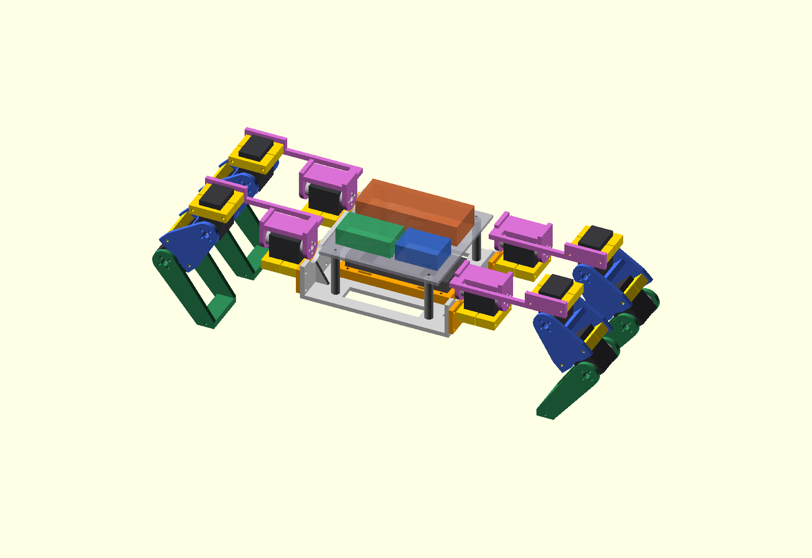
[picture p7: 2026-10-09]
mechanical/st3215-chassis.png

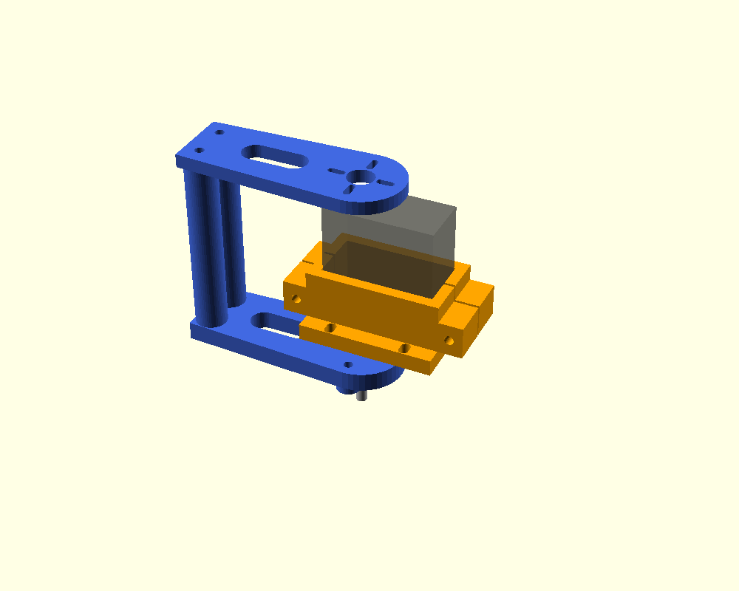
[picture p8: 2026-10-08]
mechanical/hobby-joint-preview.png

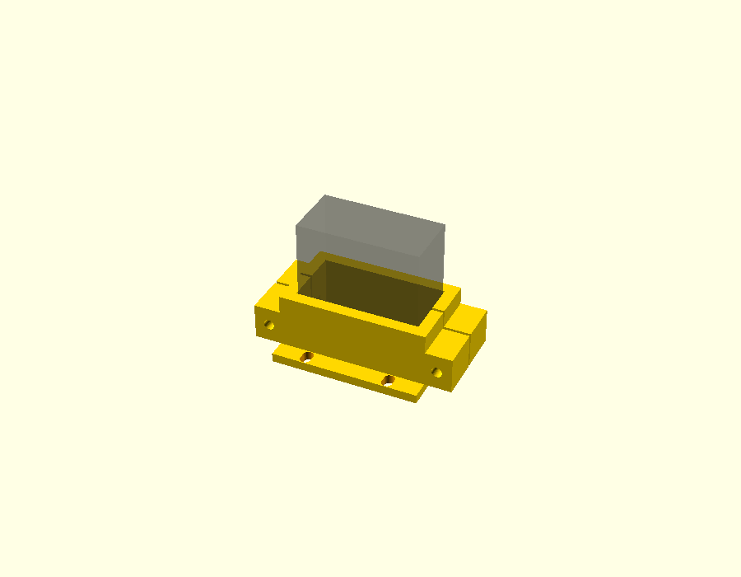
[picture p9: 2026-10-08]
mechanical/hobby-servo-cradle-preview.png

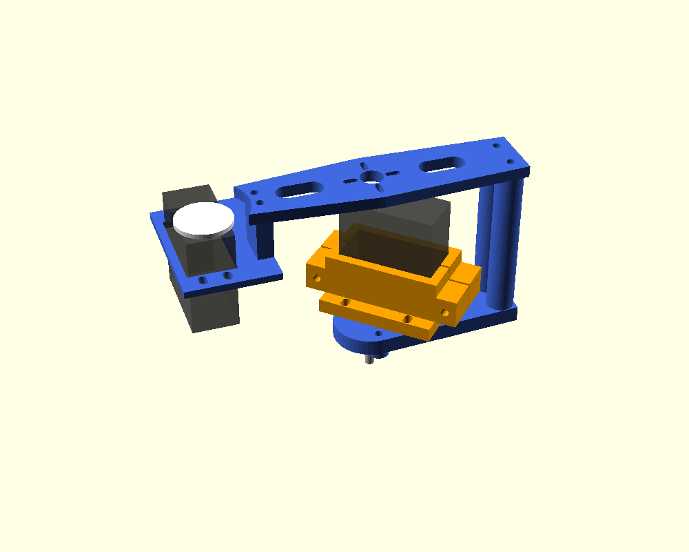
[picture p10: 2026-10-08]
mechanical/prototype-upper-leg-preview.png

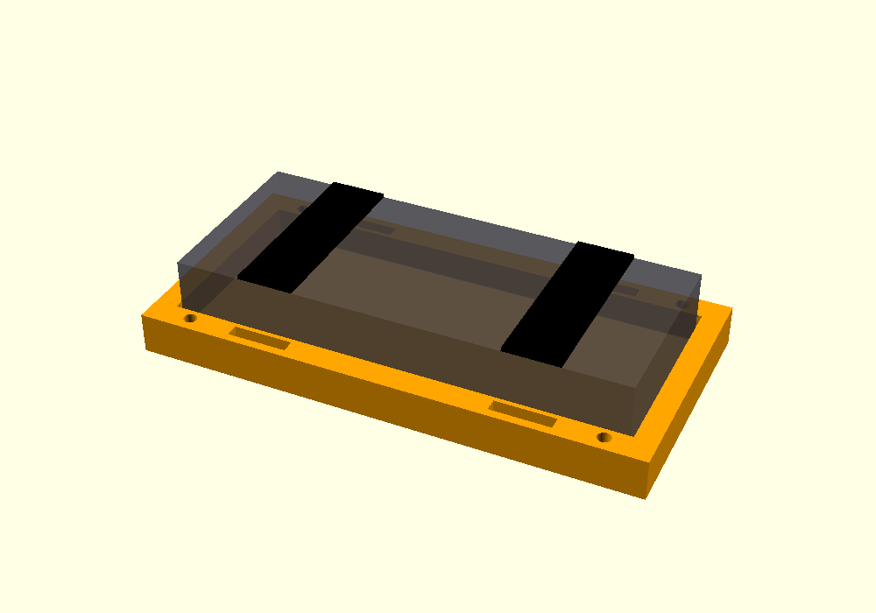
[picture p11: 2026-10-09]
mechanical/st3215-battery-tray.png

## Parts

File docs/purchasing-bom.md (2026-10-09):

# Buying BOM — active ST3215 /3S design
Last updated:2026-10-09

Buy/test one actuator first; the working leg needs three. User-selected12V
ST3215 replaces MG996R. Old MG996R manufacturing hardware and AHCT/PCA buffer
parts are no longer the active leg purchase list. DigiKey preferred for standard
electronics; actuator-specific parts may need Waveshare/compatible suppliers.

| Item | First trial /leg | Full robot | Selection /cost |
| --- | ---: | ---: | --- |
| ST3215 standard12V/30 kg.cm bus servo |1 then3|12|Selected model; landed NZD quote TBD |
| Compatible front/rear wheels |2/6|24|Verify supplied kit and rear-support behavior |
| Wheel retaining/mounting screws |Kit,up to24 per leg plus centres|Up to96 plus centres|Thread/length TBD; use supplied correct hardware |
| TTL half-duplex bus adapter |1|1 initially|Waveshare Bus Servo Adapter A candidate; no all-servo power through it |
| Servo bus cables and power-injection harness |For1 then3|12 joints|Actual pinout/current rating and lengths TBD |
| Conventional3S60 Wh LiPo |Not needed for PSU trial|1|User access; 120 x50 x20 mm assumed;mass,connector,discharge rating TBD |
|3S-compatible balance charger |1|1|Needed if not already available; model/cost TBD |
| Main fuse/holder and servo disconnect |Bench protection then robot kit|1 each|Rated and coordinated with real pack/wires; value TBD |
| Parallel power distribution and branch protection |For one leg|4 legs|40A main capacity screen; actual ratings TBD |
|3S-to5V logic buck |USB initially|1|Module/current capability TBD; DigiKey preferred |
| Cell-voltage monitor/alarm |Before battery use|1|3S balance connector compatible; part TBD |
| M3x60 through bolts/plain nuts |4 each per leg|16 each|Provisional J1/J2 mounting stacks |
| M3x65 through bolts/plain nuts |2 each per leg|8 each|Provisional J3 fork/clamp stack |
| M3 ordinary washers |12 external+4 internal per leg|112 including48 chassis/deck/tray washers|Internal0.5 mm assumed; check actual stack |
| J1 chassis M3x20 bolts/nuts |4 for one attached leg|16|10 mm plate/wall stack; provisional |
| Deck M3x70 bolts/nuts |Not needed for standalone leg|4|60 mm printed stack plus washers/nuts; provisional |
| Tray M3x25 bolts/nuts |Not needed for standalone leg|4|16 mm printed stack plus washers/nuts; provisional |
| Insulating board mounts/ties |As actual modules require|Assorted|Use generic deck slots; board fit TBD |
| Rubber/EVA foot pads |1|4|20 x56 mm cheap replaceable contact; attachment to suit |
| Printed ST3215 parts |16; optional two fit coupons first|71 installed|Four legs64, chassis/deck6, battery tray1; working layout |

Owned:ESP32-S3 N16R8,Adafruit PCA9685 (unused for current leg control),multimeter,
load cells,60V/5A adjustable supply,and Creality K2 Pro access. Battery access is
reported; no specific pack checked. No actuator,horn or bearing ownership assumed.

Waveshare lists ST3215 familyUS$16.99–21.99 depending variant: twelveUS$203.88–
263.88 before shipping,GST/conversion. This is a family price screen,not a12V
variant checkout quote. Budget targetNZ$500–800 total,ceilingNZ$1000 remains.
Servo targetNZ$25–35 each; flag actual landed pricing aboveNZ$50 or significant
budget changes before purchase. No order or supplier contact authorized here.
https://www.waveshare.com/product/st3215-servo.htm

Deferred sensor buys:one 6-axis IMU,voltage/current sensing,and forwardToF sensor.
Choose modules when those bounded stages begin; no full navigation kit purchase.

Battery mount:one st3215-battery-tray.stl,two15 mm reusable straps (>=250 mm),1 mm soft padding,and four provisional M3x25 tray bolts/nuts (included above). Tray layout provisional; pack actual fit untested.

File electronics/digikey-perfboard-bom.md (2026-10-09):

> Superseded MG996R/PWM design reference. Active design is ST3215 12V with3S power; see README.md,docs/st3215-leg-build.md and electronics/st3215-power-plan.md. These quantities,interfaces and mass estimates are not the current ST3215 design.

# DigiKey perfboard population shortlist — ELEC-007

Initial prototypes use isolated-pad perfboard. SMT is deferred until the
prototype works; DigiKey is the preferred supplier. This list populates the
complete 12-channel buffer carrier, not the motor-power distribution.
Parts remain PROVISIONAL and no order has been placed.

## Parts and quantity-adjusted cost

NZD reference prices checked from public DigiKey NZ listings/search snapshots
on 2026-10-09. Some pages could not be fetched directly and cached prices vary;
these are planning references, not a live quotation or stock reservation.
Prices exclude GST and shipping. Recheck the linked product and cart before
ordering. Reuse suitable existing parts and subtract them from these totals.

| Item | Manufacturer part | DigiKey number / public listing | Needed | Suggested pack quantity | Reference unit NZ$ | Extended NZ$ |
| --- | --- | --- | ---: | ---: | ---: | ---: |
| Quad buffer, PDIP14 | TI SN74AHCT125N | [296-4655-5-ND](https://www.digikey.co.nz/en/products/detail/texas-instruments/SN74AHCT125N/375798) | 3 | 3 | 1.69 | 5.07 |
| DIP14 socket | Assmann A 14-LC-TT | [AE9989-ND](https://www.digikey.co.nz/en/products/detail/assmann-wsw-components/A-14-LC-TT/821743) | 3 | 3 | 1.01 | 3.03 |
| 220 ohm axial resistor | Stackpole CF18JT220R | [CF18JT220RCT-ND](https://www.digikey.co.nz/en/products/detail/stackpole-electronics-inc/CF18JT220R/1741639) | 13 | 25 | 0.0352 | 0.88 |
| 10k ohm axial resistor | Stackpole CF18JT10K0 | [CF18JT10K0CT-ND](https://www.digikey.co.nz/en/products/detail/stackpole-electronics-inc/CF18JT10K0/1741566) | 24 | 25 | 0.0348 | 0.87 |
| 1k ohm axial resistor | Stackpole CF18JT1K00 | [CF18JT1K00CT-ND](https://www.digikey.co.nz/en/products/detail/stackpole-electronics-inc/CF18JT1K00/1741612) | 1 | 1 | 0.18 | 0.18 |
| 100nF radial capacitor | KEMET C322C104K5R5TA | [399-4329-ND](https://www.digikey.co.nz/en/products/detail/kemet/C322C104K5R5TA/818105) | 3 | 3 | 1.57 | 4.71 |
| Isolated-pad perfboard | BusBoard PAD2 | [4526-PAD2-ND](https://www.digikey.co.nz/en/products/detail/busboard-prototype-systems/PAD2/19200351) | 1 | 1 | 13.64 | 13.64 |
| Breakaway 40-pin male strip | Sullins PRPC040SAAN-RC | [S1011EC-40-ND](https://www.digikey.co.nz/en/products/detail/sullins-connector-solutions/PRPC040SAAN-RC/2775214) | 41 header positions | 2 strips | 2.22 | 4.44 |

Reference component subtotal **NZ$32.82 excluding GST/shipping**, or **NZ$37.74
with 15% GST before shipping**. Allow about NZ$40 before shipping for these
components; this is not the complete harness or robot cost. No expensive
regulator, battery or motor connector is selected by this list. Insulated
hookup wire, solder, insulation, removable mounting supports and mating signal
leads are additional/reusable workshop items, not included in this subtotal.
Listings indicated available stock when indexed; confirm availability at checkout.

For just the first one-servo bench, do not buy all three buffer blocks unless
wanted for later: retain its existing small harness and staged testing plan.
The quantity-25 resistor packs provide inexpensive spares; no reel is required.

## Compatibility check

- SN74AHCT125N is the through-hole AHCT device already specified by the harness:
  PDIP14, 2.54mm pin pitch, 7.62mm row spacing. Its 4.5–5.5V supply range
  covers the provisional switched 5.2V rail with 5.3V maximum. TTL input levels
  accept 3.3V logic. Keep the common active-low OE wiring and chip orientation.
  [TI primary datasheet](https://www.ti.com/lit/ds/symlink/sn74ahct125.pdf).
- A 14-LC-TT has 14 pins, 2.54mm pitch and 7.62mm row spacing, matching the
  layout. Socket bodies/notches must still be dry fitted; no physical clearance
  is claimed. [Assmann primary product data](https://www.assmann-wsw.com/us/product/a-14-lc-tt/).
- CF18 resistors are 1/8W, 5%, axial, nominal 3.3mm long by 1.7mm diameter.
  Their small bodies suit adjacent 2.54mm rows and 10.16mm formed lead span.
  Normal worst pull-down dissipation is under 3mW at 5.3V; the 1k pull-up
  dissipates about 11mW at 3.3V. Series parts carry signal current, not motor
  current. This is a normal-operation rating check, not a short-circuit test.
  [Stackpole primary catalog, CF series](https://www.seielect.com/catalog/sei-catalog.pdf).
- C322C104K5R5TA is 100nF, 50V, X7R, 10%, with 5.08mm formed lead spacing.
  Its nominal body is 5.08 x3.18mm, maximum seated height 6.60mm. The two-row
  spacing matches C1..C3; keep local decoupling wires short.
  [KEMET primary Goldmax datasheet](https://yageogroup.com/content/datasheet/asset/file/KEM_C1050_GOLDMAX_X7R).
- PAD2 is 100 x80 x1.6mm FR4, with a 31 x39 hole pattern on 2.54mm pitch,
  double-sided isolated pads and 0.94mm holes. Orient the 39-hole dimension
  horizontally for the logical 35 x25 layout. Reserve **100 x80mm**, rather
  than the earlier generic 100 x70mm estimate. Choose a usable central grid
  origin during dry fit, avoiding its four corner mounting holes. The published
  pattern fits the required grid count; actual pad/body/mount clearance remains
  untested. No cutting or chassis adoption is required by this shortlist.
  [BusBoard primary data](https://www.busboard.com/PAD2),
  [datasheet](https://www.busboard.com/documents/datasheets/BPS-DAT-%28PAD2%29-Datasheet.pdf).
- PRPC040SAAN-RC is a single-row, straight through-hole, breakaway 2.54mm header.
  Cut 3 x6 input, 3 x4 output, 3 x3 supply and 1 x2 CTRL sections: **41 positions**.
  The supply sections use the two outer pins, 5.08mm apart; remove the centre
  pin and leave its pad unwired. One 40-pin strip is insufficient. Use the
  supplier's linked Sullins drawing to check the purchased lead/body variant,
  then dry fit in the 0.94mm holes. These unkeyed headers need clear polarity
  labels and suitable matching female leads. Their use is limited to signals,
  logic reference and buffer supply; no servo motor current goes through them.

The original pad coordinates, net endpoints and 12 signal chains are unchanged.
Existing independent checker: `node electronics/check-buffer-perfboard.mjs`.
No physical fit, soldering, powered operation or final SMT footprint is verified.

## Later SMT revision

Retain the same functional netlist and enable behavior as the starting point.
After measurements, consider SOIC AHCT125 and commodity SMT resistors/capacitors
on a simple PCB. Recheck package pinouts, decoupling, connector placement and
actual current paths then. Do not copy the PDIP placement as a PCB footprint.

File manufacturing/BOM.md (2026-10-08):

# Buying BOM — one integrated bench leg

Provisional MG996R fit; buy/test one servo before ordering all12. Use supplied horns and original centre screws. Owned ESP32-S3/PCA9685 boards need no replacements.

| Item | Qty |
| --- | ---: |
| MG996R positional servo/horn/centre screw | 3 |
| 624 bearing,4 x13 x5mm nominal | 3 |
| M3 x40 through bolt | 4 |
| M3 x20 through bolt | 8 |
| M3 x16 through bolt | 9 |
| M3 x12 through bolt | 4 |
| M3 x70 through bolt | 2 |
| M3 nut | 27 |
| M3 ordinary flat washer | 53 |
| M3 washer,12mm OD backing | 1 |
| M4 x35 pivot / locknut / washer | 3 each |
| M2 x10 horn bolt / nut / washer | Up to12 /12 /24 |
| Rubber/EVA foot pad,18 x8 x1mm assumed | 1 |
| Small cable tie | 4 |

Bench-only: two M4 anchors/nuts/washers and two40mm standoffs(max10mm OD); choose bolt length for the actual rigid vertical board. Reuse existing hardware packs. Prices are unverified; budget unchanged. No M3x90 bridge bolts or J1 tab bolts are needed.

Electrical commissioning uses the separate bench wiring plan; never power servos through the controller boards. The adjustable60V/5A supply must be set near5.2V; its5A rating permits staged tests rather than the7.5A three-servo planning target. No robot battery/regulator purchase is selected here.

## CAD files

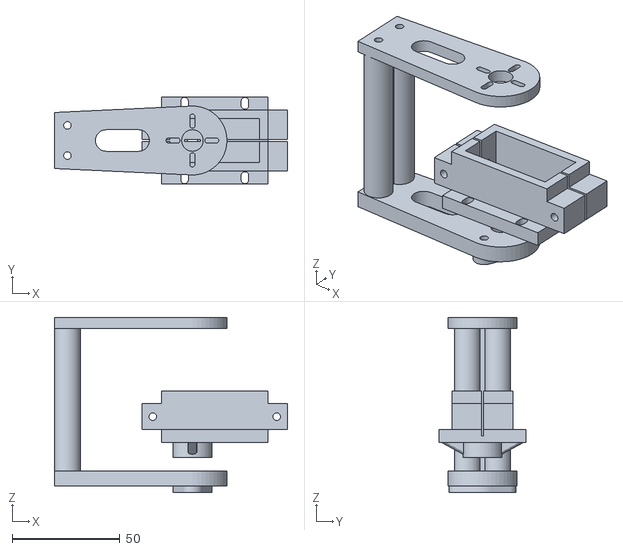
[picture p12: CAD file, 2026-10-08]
mechanical/hobby-joint-assembly.stl
108.1 x 40.5 x 81.2

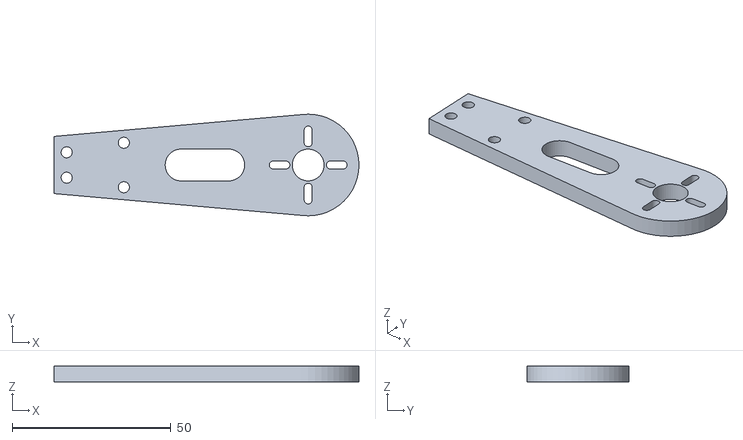
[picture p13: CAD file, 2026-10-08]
docs/manufacturing-verification/prototype-lower-leg.stl
96.0 x 32.0 x 5.00

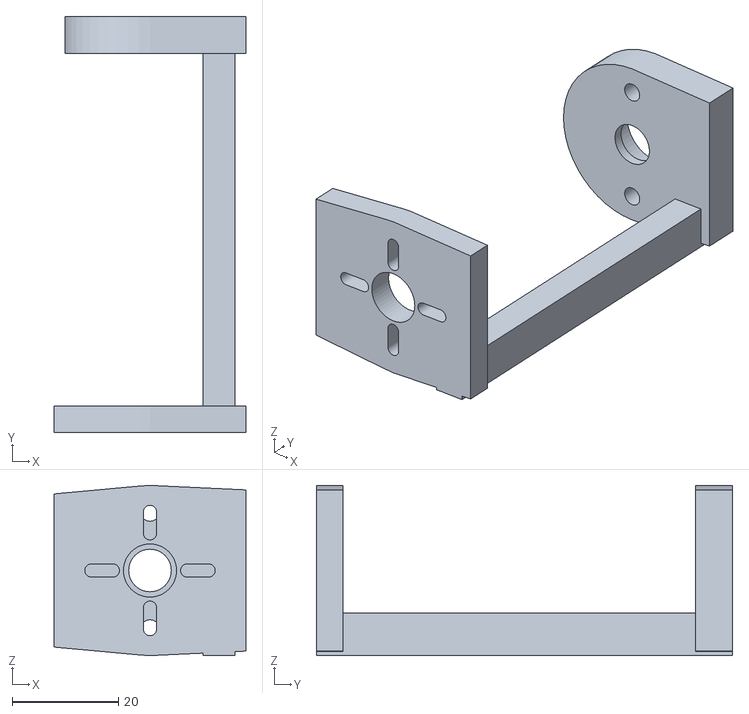
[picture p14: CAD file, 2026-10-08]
manufacturing/coupons/prototype-fork-fit-coupon.stl
36.0 x 78.2 x 32.0

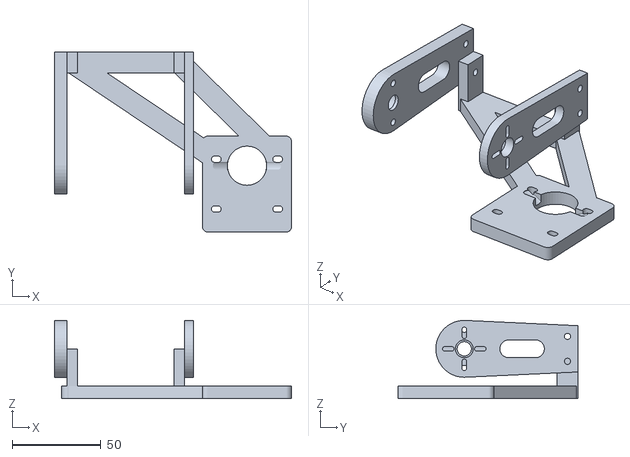
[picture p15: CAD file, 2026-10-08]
manufacturing/stl/prototype-integrated-hip.stl
133.2 x 101.3 x 44.0

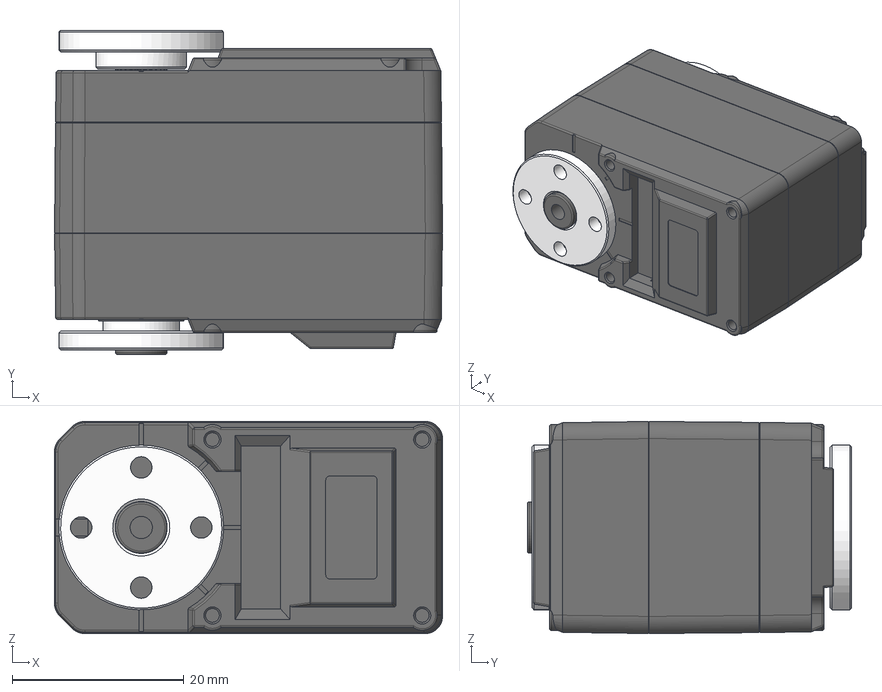
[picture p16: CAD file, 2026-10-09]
mechanical/reference/st3215/ST3215.step
45.2 x 37.8 x 24.7 mm
ZK_122
SG-ZIJI_15
XG-ZIJI_16
MOTOR-1723_3
PCB-CHAZUO_92
GE_27
金属舵盘（驱动）
金属舵盘（从动）

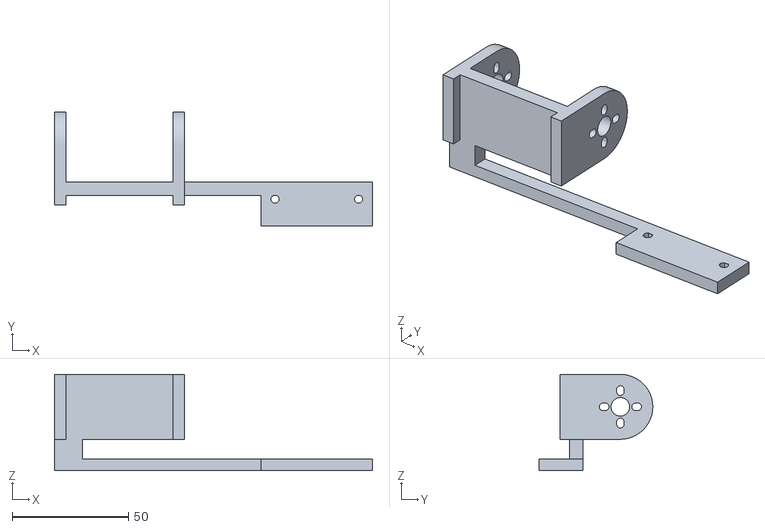
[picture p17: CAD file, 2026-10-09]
mechanical/st3215-hip.stl
137.0 x 49.0 x 41.5

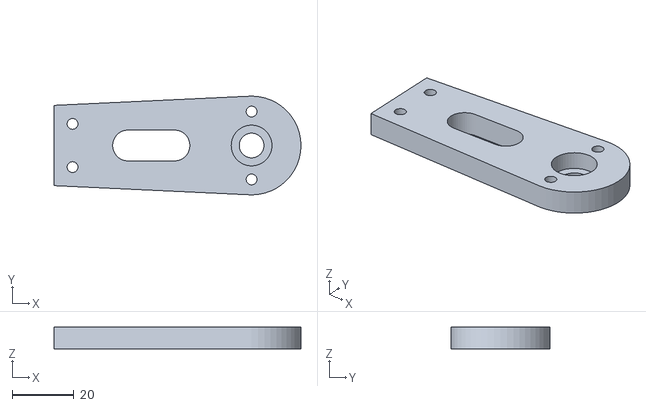
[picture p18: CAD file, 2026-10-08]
docs/manufacturing-verification/hobby-joint-rear-arm.stl
80.0 x 32.0 x 7.00

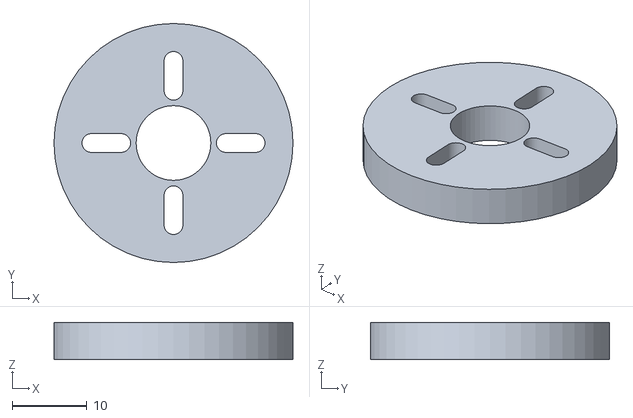
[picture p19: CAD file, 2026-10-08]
manufacturing/coupons/hobby-joint-horn-coupon.stl
32.0 x 32.0 x 5.00

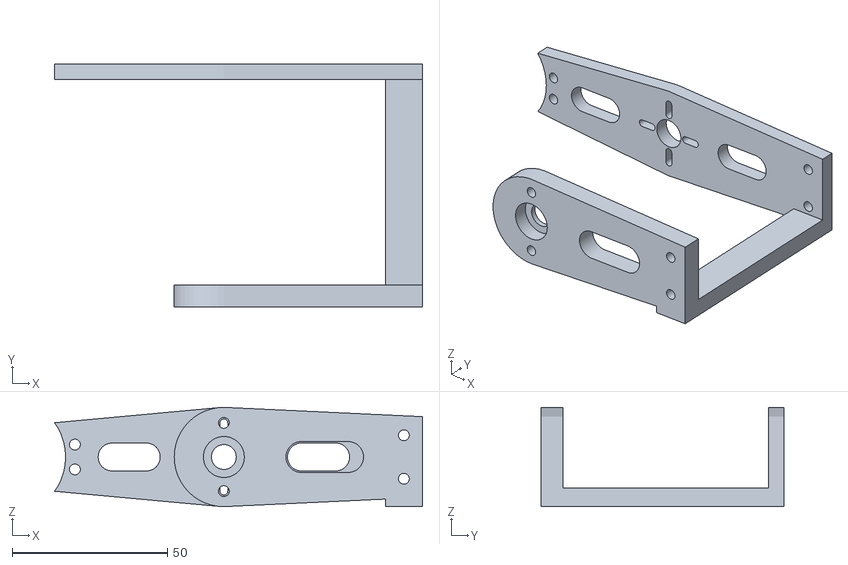
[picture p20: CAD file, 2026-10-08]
manufacturing/stl/prototype-pitch-fork-upper-mirrored.stl
118.6 x 78.2 x 32.0

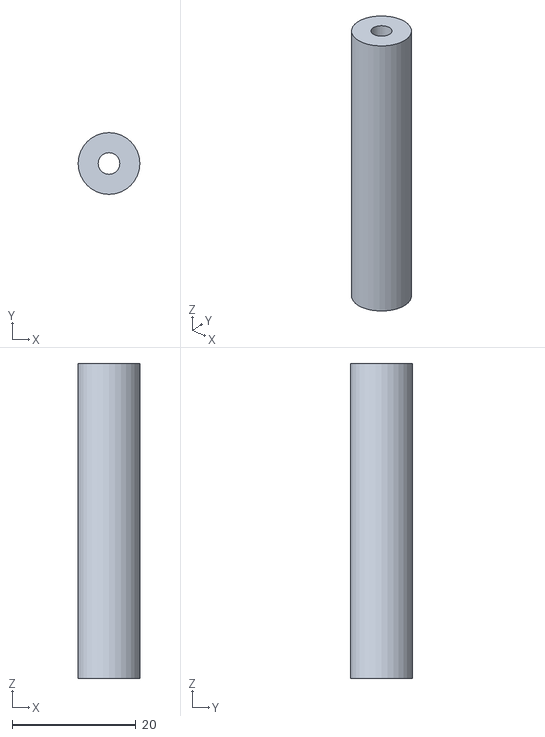
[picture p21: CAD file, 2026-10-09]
mechanical/st3215-chassis-riser.stl
10.0 x 10.0 x 51.0

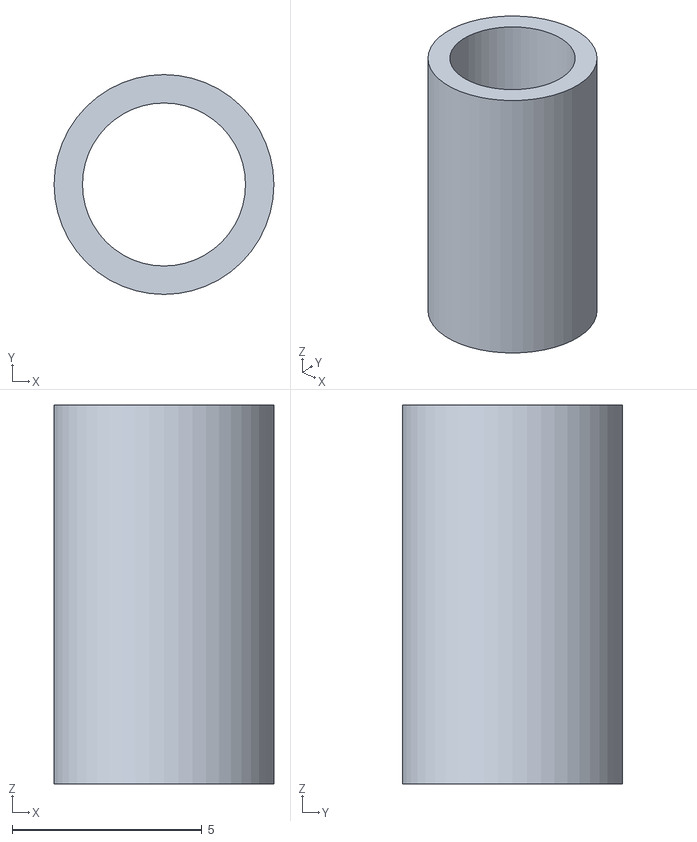
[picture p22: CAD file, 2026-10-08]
docs/manufacturing-verification/prototype-knee-spacer.stl
5.80 x 5.80 x 10.0

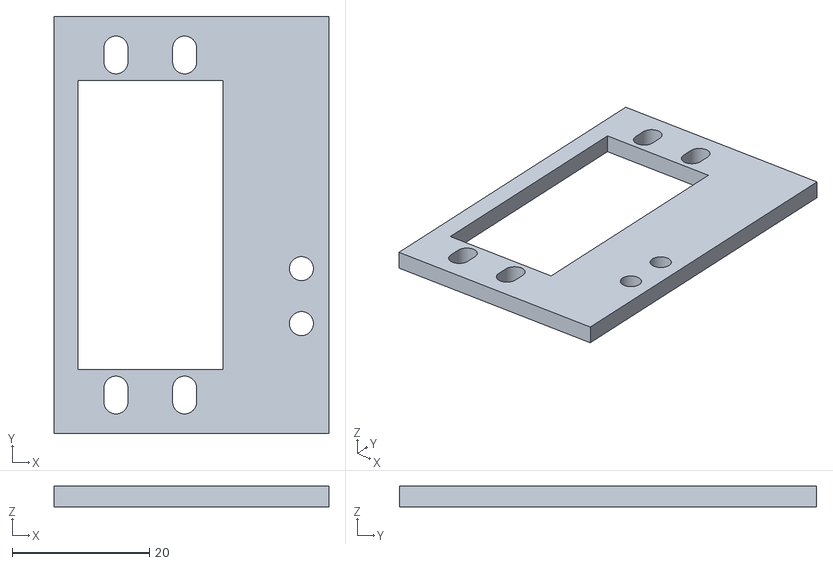
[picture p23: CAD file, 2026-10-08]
manufacturing/coupons/prototype-upper-leg-ear-coupon.stl
40.0 x 60.7 x 3.00

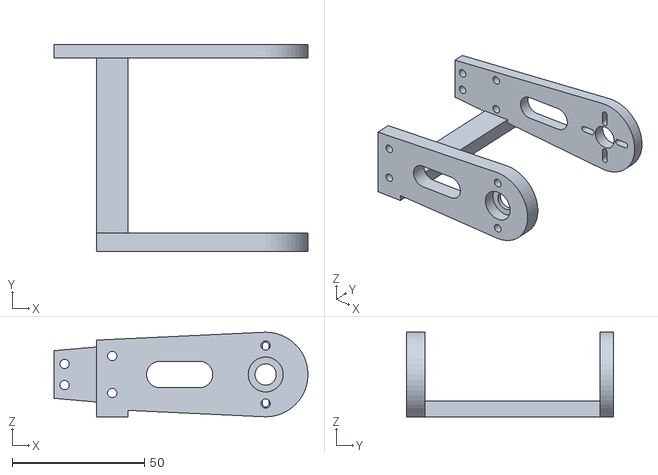
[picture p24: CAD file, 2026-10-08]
manufacturing/stl/prototype-pitch-fork-lower-mirrored.stl
96.0 x 78.2 x 32.0

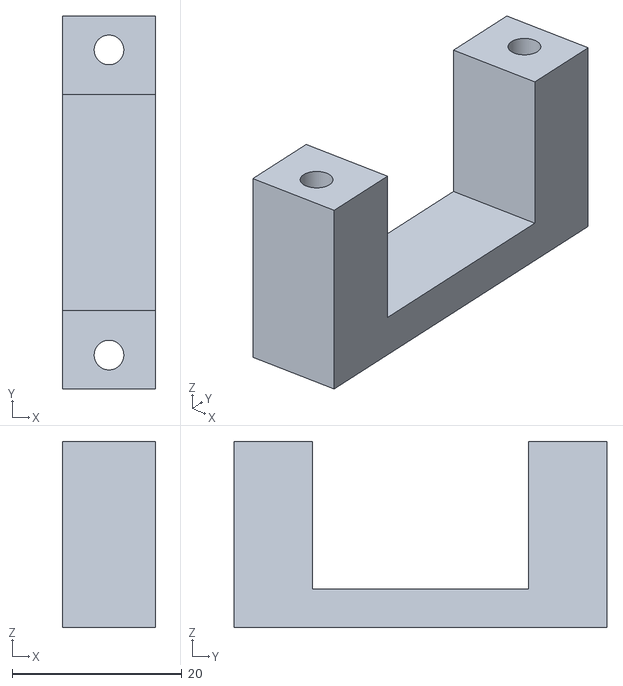
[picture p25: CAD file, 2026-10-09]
mechanical/st3215-clamp-top.stl
11.0 x 44.0 x 22.0

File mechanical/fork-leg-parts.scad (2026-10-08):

// MEC-162 experimental leg; original supported manufacturing kit unchanged.
module fork_leg_fixed(){
multmatrix([[0,0,1,0],[1,0,0,10.349999999999994],[0,1,0,0],[0,0,0,1]]) color("gold") import("hobby-servo-cradle-left.stl"); // J1 cradle left
multmatrix([[0,0,1,0],[1,0,0,10.349999999999994],[0,1,0,0],[0,0,0,1]]) color("gold") import("hobby-servo-cradle-right.stl"); // J1 cradle right
multmatrix([[0,1.2246467991473532e-16,-1,0],[1,0,0,10.349999999999994],[0,-1,-1.2246467991473532e-16,0],[0,0,0,1]]) color("gold") import("hobby-joint-support.stl"); // J1 support
multmatrix([[0,0,1,-18],[1,0,0,0],[0,1,0,0],[0,0,0,1]]) color("gold") import("hobby-joint-front-spacer.stl"); // J1 8mm spacer
multmatrix([[0,0,1,-26],[1,0,0,0],[0,1,0,0],[0,0,0,1]]) color("gold") import("hobby-joint-rear-spacer.stl"); // J1 3mm spacer
multmatrix([[0,0,1,-10],[1,0,0,10.35],[0,1,0,0],[0,0,0,1]]) color("gold") import("prototype-bench-base.stl"); // Bench adapter
multmatrix([[0,0,1,0],[1,0,0,0],[0,1,0,0],[0,0,0,1]]) color([.25,.25,.25,.6]) translate([-10,-9.85,3]) cube([40.7,19.7,42.9]);
}
module fork_leg_j1(){
multmatrix([[0,0,1,50],[6.123233995736766e-17,-1,0,0],[1,6.123233995736766e-17,0,0],[0,0,0,1]]) color("gold") import("hobby-joint-front-arm.stl"); // J1 front arm
multmatrix([[0,1.2246467991473532e-16,-1,-16.200000000000003],[6.123233995736766e-17,1,1.2246467991473532e-16,0],[1,-6.123233995736766e-17,-7.498798913309288e-33,0],[0,0,0,1]]) color("gold") import("hobby-joint-rear-arm.stl"); // J1 rear arm
multmatrix([[0,1.2246467991473532e-16,-1,-23.200000000000003],[6.123233995736766e-17,1,1.2246467991473532e-16,0],[1,-6.123233995736766e-17,-7.498798913309288e-33,0],[0,0,0,1]]) color("gold") import("hobby-joint-retainer.stl"); // J1 retainer
multmatrix([[1,0,0,0],[0,0,1,-28],[0,-1,0,0],[0,0,0,1]]) color("gold") import("prototype-j1-carrier-mirrored.stl"); // J1 carrier
}
module fork_leg_j2(){
multmatrix([[0,1,0,85],[0,0,1,-18],[1,0,0,10.349999999999994],[0,0,0,1]]) color("gold") import("hobby-servo-cradle-right.stl"); // J2 cradle left
multmatrix([[0,1,0,85],[0,0,1,-18],[1,0,0,10.349999999999994],[0,0,0,1]]) color("gold") import("hobby-servo-cradle-left.stl"); // J2 cradle right
multmatrix([[0,-1,1.2246467991473532e-16,85],[0,-1.2246467991473532e-16,-1,-18],[1,0,0,10.349999999999994],[0,0,0,1]]) color("gold") import("hobby-joint-support.stl"); // J2 support
multmatrix([[0,-1,0,85],[0,0,1,-36],[-1,0,0,0],[0,0,0,1]]) color("gold") import("hobby-joint-front-spacer.stl"); // J2 8mm spacer
multmatrix([[0,-1,0,85],[0,0,1,-44],[-1,0,0,0],[0,0,0,1]]) color("gold") import("hobby-joint-rear-spacer.stl"); // J2 3mm spacer
multmatrix([[0,1,0,85],[0,0,1,-18],[1,0,0,0],[0,0,0,1]]) color([.25,.25,.25,.6]) translate([-10,-9.85,3]) cube([40.7,19.7,42.9]);
}
module fork_leg_upper(){
multmatrix([[0.6952682860952114,0.7187503115479167,8.802152684233191e-17,85],[0,1.2246467991473532e-16,-1,-41.2],[-0.7187503115479167,0.6952682860952114,8.514580811151668e-17,0],[0,0,0,1]]) color("gold") import("hobby-joint-retainer.stl"); // J2 retainer
multmatrix([[-0.6952682860952114,0.7187503115479167,0,85],[0,0,1,10],[0.7187503115479167,0.6952682860952114,0,0],[0,0,0,1]]) color("gold") import("prototype-upper-leg-saddle-mirrored.stl"); // Knee saddle
multmatrix([[-0.6952682860952114,0.7187503115479167,0,102.03407300933267],[0,0,1,37],[0.7187503115479167,0.6952682860952114,0,-17.609382632923968],[0,0,0,1]]) color("gold") import("prototype-cable-guide.stl"); // Cable guide
multmatrix([[-0.6952682860952114,0.7187503115479167,0,133.6687800266648],[0,0,1,-26],[0.7187503115479167,0.6952682860952114,0,-50.31252180835418],[0,0,0,1]]) color("gold") import("prototype-knee-support.stl"); // Knee support
multmatrix([[0.6952682860952114,-0.7187503115479167,0,133.6687800266648],[0,0,1,-36],[-0.7187503115479167,-0.6952682860952114,0,-50.31252180835418],[0,0,0,1]]) color("gold") import("prototype-knee-spacer.stl"); // Knee 10mm spacer
multmatrix([[0.6952682860952114,-0.7187503115479167,0,133.6687800266648],[0,0,1,-44],[-0.7187503115479167,-0.6952682860952114,0,-50.31252180835418],[0,0,0,1]]) color("gold") import("hobby-joint-rear-spacer.stl"); // Knee 3mm spacer
multmatrix([[-0.6952682860952114,4.4010763421165954e-17,-0.7187503115479167,96.50000498476666],[0,1,6.123233995736766e-17,-18],[0.7187503115479167,4.257290405575834e-17,-0.6952682860952114,11.124292577523383],[0,0,0,1]]) color("royalblue") import("prototype-pitch-fork-upper-mirrored.stl"); // Upper fork
multmatrix([[-0.7187503115479167,-0.6952682860952114,0,133.6687800266648],[0,0,1,-18],[-0.6952682860952114,0.7187503115479167,0,-50.31252180835418],[0,0,0,1]]) color([.25,.25,.25,.6]) translate([-10,-9.85,3]) cube([40.7,19.7,42.9]);
}
module fork_leg_lower(){
multmatrix([[-0.5725752255153884,0.8198521885840168,1.0040293585233684e-16,133.6687800266648],[0,1.2246467991473532e-16,-1,-41.2],[-0.8198521885840168,-0.5725752255153884,-7.012024171984944e-17,-50.31252180835418],[0,0,0,1]]) color("gold") import("hobby-joint-retainer.stl"); // Knee retainer
multmatrix([[0.5725752255153884,0.8198521885840168,0,90.15306288749528],[0,0,1,29],[0.8198521885840168,-0.5725752255153884,0,-112.62128814073944],[0,0,0,1]]) color("gold") import("prototype-foot.stl"); // Foot carrier
multmatrix([[0.5725752255153884,5.020146792616842e-17,-0.8198521885840168,146.78641504400906],[0,1,6.123233995736766e-17,-18],[0.8198521885840168,-3.506012085992472e-17,0.5725752255153884,-59.47372541660039],[0,0,0,1]]) color("royalblue") import("prototype-pitch-fork-lower-mirrored.stl"); // Lower fork
}
module upper_delta(q2){translate([85,-18,0]) rotate([0,-(q2-44.0486),0]) translate([-85,18,0]) children();}
module lower_delta(q3){translate([133.6687800266648,-18,-50.31252180835418]) rotate([0,q3-78.9786,0]) translate([-133.6687800266648,18,50.31252180835418]) children();}
module fork_leg(q1=0,q2=44.0486,q3=78.9786){fork_leg_fixed();rotate([q1,0,0]){fork_leg_j1();fork_leg_j2();upper_delta(q2){fork_leg_upper();lower_delta(q3) fork_leg_lower();}}}
module placed_upper(){multmatrix([[-0.6952682860952114,4.4010763421165954e-17,-0.7187503115479167,96.50000498476666],[0,1,6.123233995736766e-17,-18],[0.7187503115479167,4.257290405575834e-17,-0.6952682860952114,11.124292577523383],[0,0,0,1]]) import("prototype-pitch-fork-upper-mirrored.stl");}
module placed_lower(){multmatrix([[0.5725752255153884,5.020146792616842e-17,-0.8198521885840168,146.78641504400906],[0,1,6.123233995736766e-17,-18],[0.8198521885840168,-3.506012085992472e-17,0.5725752255153884,-59.47372541660039],[0,0,0,1]]) import("prototype-pitch-fork-lower-mirrored.stl");}
module only_forks(q1=0,q2=44.0486,q3=78.9786){rotate([q1,0,0]) upper_delta(q2){placed_upper();lower_delta(q3) placed_lower();}}

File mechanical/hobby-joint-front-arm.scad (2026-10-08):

include <hobby-joint-common.scad>
module front_arm() {
    difference() {
        arm_blank(front_t);
        arm_window(front_t);
        translate([0,0,-1]) cylinder(d=10,h=front_t+2);
        for(a=[0,90,180,270]) rotate([0,0,a]) hull()
            for(r=[7,11]) translate([r,0,-1]) cylinder(d=2.5,h=front_t+2);
        bridge_holes(front_t);
    }
}
front_arm();

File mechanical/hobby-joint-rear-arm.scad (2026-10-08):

include <hobby-joint-common.scad>
module rear_arm() {
    difference() {
        arm_blank(rear_t);
        arm_window(rear_t);
        translate([0,0,-1]) cylinder(d=8,h=rear_t+2);
        translate([0,0,rear_t-seat_depth]) cylinder(d=seat_d,h=seat_depth+1);
        for(y=[-11,11]) translate([0,y,-1]) cylinder(d=3.5,h=rear_t+2);
        bridge_holes(rear_t);
    }
}
rear_arm();

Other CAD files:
docs/manufacturing-verification/hobby-joint-horn-coupon.stl
manufacturing/coupons/hobby-servo-cradle-coupon.stl
manufacturing/stl/prototype-j1-carrier-mirrored.stl
mechanical/st3215-upper.stl
mechanical/hobby-servo-cradle.scad
ARCHIVE/MFG-002-three-dof-bench-2/cad/hobby-joint-assembly.scad
ARCHIVE/MFG-002-three-dof-bench-2/cad/prototype-pitch-leg.scad
ARCHIVE/MFG-002-three-dof-bench-2/cad/prototype-three-dof-leg.scad
ARCHIVE/MFG-002-three-dof-bench-2/cad/prototype-upper-leg-assembly.scad
ARCHIVE/MFG-002-three-dof-bench-2/stl/prototype-j1-carrier.stl
ARCHIVE/MFG-002-three-dof-bench-2/stl/prototype-upper-leg-saddle.stl
ARCHIVE/MFG-002-three-dof-bench-3/cad/hobby-joint-bearing-parts.scad
ARCHIVE/MFG-002-three-dof-bench-3/cad/hobby-joint-bridge.scad
ARCHIVE/MFG-002-three-dof-bench-3/cad/hobby-joint-common.scad
ARCHIVE/MFG-002-three-dof-bench-3/cad/hobby-joint-fit-samples.scad
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

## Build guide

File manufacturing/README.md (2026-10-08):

# MFG-003 — integrated single-leg build checkpoint

Experimental integrated-bench-1:23 printed assembly pieces, three MG996R candidates, five fit coupons. Physical fit/load/powered operation NOT_PERFORMED. This is a print and unpowered assembly checkpoint.

Start with [printing](docs/printing.md), [print list](docs/print-list.md), [assembly](docs/assembly.md), and [buying BOM](BOM.md). Open cad/prototype-integrated-bench-pack-assembly.scad for the self-contained nominal assembly. Editable CAD and all imported STLs are included; OpenSCAD is not bundled.

Original integrated hip, mirrored upper/lower pitch forks and mirrored knee saddle are deliberate physical print hands. Bearings, horns and fasteners are described in the guide but not all drawn. The previous bench-3 pack is preserved under ARCHIVE/MFG-002-three-dof-bench-3 in the repository. Complete robot2kg compliance is not established.

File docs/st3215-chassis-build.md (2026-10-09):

# ST3215 four-leg chassis — working prototype

Assembly CAD: `mechanical/st3215-chassis.scad`; preview: `mechanical/st3215-chassis.png`.
This is an untested working layout, not a manufacturing release. Verify one servo
kit and first-leg fit before repeating the leg prints.

## Printed assembly

| Part | Quantity | Print envelope / purpose |
| --- | ---: | --- |
| st3215-chassis-body.stl | 1 | 175 x160 x42 mm; floor, end walls and hip reliefs |
| st3215-chassis-deck.stl | 1 | 140 x140 x4 mm; removable generic mounting deck |
| st3215-chassis-riser.stl | 4 | Diameter10 x51 mm; deck spacers |
| st3215-battery-tray.stl | 1 | Existing central padded battery holder |
| Current leg parts | 4 sets | Sixteen installed pieces per leg; see leg build guide |

Total71 installed printed pieces, including the tray. The two fit coupons are
alternative trial parts and are not added to this count. All three new STLs are
bed-oriented; inspect holes, thin features and local bridges in the slicer.
Use the existing PLA+/PETG prototype approach and at least four perimeters.
Actual material, infill mass and stiffness need the first print/load trial.

## Placement and mounting

Body frame: +x forward, +y left, +z up; z=0 is the hip shaft reference plane.
Hip origins: FL[115,50,0], FR[115,-50,0], RL[-115,50,0], RR[-115,-50,0] mm.
Front legs use the existing assembly orientation; rear legs rotate180 degrees
about z. There are no mirrored leg prints. The long hip carriers point away from
the central body. This reuses the current leg geometry at the cost of a long
footprint; nominal foot reference spacing is about400 x100 mm.

Bolt each existing J1 mounting plate to an end wall through its four fixture
holes:16 M3x20 bolts/nuts and32 washers provisionally. The wall and plate stack
is10 mm; check actual washer/nut engagement and protrusion. The34 mm hub relief
clears the rotating hip fork. Keep these reliefs and cable access open.

This layout does not establish servo calibration. Outward source-J1 sign is
FL+, FR-, RL-, RR+; rear rotations also affect body-to-leg coordinates.
Firmware must use the actual frames and measured joint directions/limits.

## Battery and removable deck

The tray bolts centrally to the floor with four M3x25 bolts/nuts and eight
washers provisionally. The bolts go through the11 mm tray side walls and5 mm
floor; heads/washers stay outside the pouch footprint. Verify no sharp hardware
contacts the cells. Add soft padding and the two existing15 mm battery straps.
Battery remains the provisional120 x50 x20 mm pack. Leads, connector, swelling,
actual dimensions and cell condition remain unverified.

The padded battery top is z=-19 mm; deck underside is z=8 mm, leaving27 mm
nominal clearance (26 mm above the modeled strap). Lead/connector routing can
use the open sides; bend radius and strain relief await the actual pack.
Remove the deck to release the battery straps. Remove/disconnect the battery
for charging and use an appropriate balance charger.

Four printed51 mm risers at x=+/-55,y=+/-60 mm support the deck. Use four
M3x70 through bolts/nuts and eight washers provisionally. The printed stack is
60 mm including floor and deck; verify actual thread engagement/protrusion.
Deck fasteners remain clear of the reserved module spaces.

Green65 x35 x20 mm, blue50 x35 x20 mm and orange120 x45 x25 mm blocks reserve
space for the ESP32, bus adapter and power/buck/fuse wiring respectively. These
are provisional allowances, not dimensional models or selected electronics.
Use insulating standoffs or secured perfboard/boards with the generic slots;
confirm real headers, USB connectors, switch access and tool clearance.
Keep the main motor-current distribution in rated wiring/connectors. The deck
and perfboard do not provide electrical protection. An accessible disconnect
and actual fuse/buck/harness selection remain separate pending work.

## Verification and limits

Run `node mechanical/verify-st3215-chassis.mjs` for a read-only check of current
source/report/STL identity. Run `node mechanical/check-st3215-chassis.mjs` to regenerate chassis STLs and
validate mesh connectivity, bed size and all fixture/deck/tray/riser bores.
Conservative component boxes exclude other body/leg and inter-leg collisions;
actual exported hip meshes then check the hub relief at source outward J1=0 and
5 degrees. These two poses do not release a swept or loaded motion range.

The geometric body centre lies within the nominal four-foot reference rectangle,
with50 mm lateral margin. This is not a measured centre of mass, three-leg
support margin or walking qualification. Weight shifting is needed before a
crawl; actual battery/servo/electronics mass must be measured.
Nominal floor-to-contact clearance is72 mm before fastener protrusions or pads.

Chassis/deck/risers have a combined solid-PETG estimate of about331 g at
1.24 g/cm3. This excludes the tray, legs, hardware and electronics, and differs
from actual sliced mass. Extra weight remains subject to loaded servo tests.
No FEA, dynamic gait, physical load test or powered operation was performed.

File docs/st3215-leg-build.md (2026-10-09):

# ST3215 first-leg working design

Open mechanical/st3215-leg.scad; default view is the assembled nominal leg.
Parts are working prototypes,not a released manufacturing pack. The earlier
MFG-003 pack is MG996R-specific and must not be used for this design.

| STL | Pieces per leg | Purpose |
| --- | ---: | --- |
| st3215-clamp-bottom.stl |3| Fixed-case clamp halves |
| st3215-clamp-top.stl |3| Opposite clamp halves |
| st3215-hip.stl |1| J1 output and J2 fixed-case carrier |
| st3215-upper.stl |1| J2 output and J3 fixed-case support |
| st3215-lower.stl |1| J3 output;85 mm contact datum |
| st3215-mount.stl |1| J1 fixed-case mounting plate |
| st3215-shims.stl |3| Front wheel spacers |
| st3215-shim-rear.stl |3| Independently adjustable rear wheel spacers |

Three12V ST3215s and six supplied-compatible wheels complete the joint interfaces.
Check the opposite wheel is a proper free support and confirm supplied hardware;
do not bolt the fork to a stationary rear case boss. No old624/M4 pivot is assumed.

Servo local shaft axis is+Z; body extends x=-10.11..35.11 mm. Pocket has0.8 mm
total allowance,1 mm clamp split gap and11 mm-long grip on the tail section.
Clamps close gently with through bolts outside the case; do not crush the shell
or bridge a connector. Actual body shape/ports may require clamp relocation. The drawing distinguishes29 mm main shell from35 mm overall case features. This conservative35.8 mm pocket may require reducing case_grip_height to the actual grip band or fitting firm removable liners; do not assume tightening can close a6 mm gap. Print/check one pair before complete leg.
Forks use5 mm plates at axial±23..28 mm,with a6 mm connecting web clear of the
case. Upper link fixes the next servo's case; lower link moves with that servo's
front wheel and opposite support wheel. Link axes remain70/85 mm apart.

The mounting plate has a notch clearing the rotating J1 hub and bolts the J1 clamp to a rigid vertical bench fixture or future
chassis. It is not a freestanding bench base. Secure the fixture before loading.
J2 bolts clamp to the hip carrier; J3 clamp bolts pass through both upper-fork
plates. Two0.5 mm spacer washers at each J3 bolt bridge nominal clamp/fork gaps.
Nominal M3 clamp bolts: fourx60 (J1/J2) and twox65 (J3),plain nuts/washers;
actual stacks/thread engagement/protrusion must be checked before buying.
J1 fixture screws depend on fixture thickness; start with fourM3 through bolts.

Wheel OD19.2 mm,PCD14 mm and total37.25 mm come from the downloaded drawing.
The drawing title saysSCS215 although linked from the ST3215 manufacturer page.
Front and rear face distances are separately configurable as `wheel_face_front`
and `wheel_face_rear` (positive magnitudes from the shaft datum). Both default
to18.625 mm provisionally. Each spacer is derived as23 mm minus its face distance;
nominal thickness remains4.375 mm. Measure each side independently; do not force
the fork against the bearings. `shims` selects front, `shim-rear` selects rear.
A face outside the fork planes fails rather than producing a negative spacer.
Horn holes are radial6.5..7.5 mm slots,Ø3.2; use correct supplied screws and
washers after confirming thread size and engagement. CentreØ8 access permits
wheel retaining screw access. The printed clamp avoids unknown case screw threads.

Print PLA+/PETG,0.4 mm nozzle,0.2 mm layers,at least4 perimeters,moderate infill.
Files are bed-oriented. Upper and hip parts need local support under bridging
features; inspect slicer preview,especially holes and the hip bridge. Do not infer
support-free printing from an STL bounding-box check. Print one clamp pair and
wheel spacer first,then revise fit as needed. Sixteen pieces is a prototype count,
not an instruction to print four full legs before the first works.

Nominal foot point is approximately[85,0,-120]mm before J1 rotation,not the old
MG996R[85,32,-120] datum. The lower tip has a flat20 x56 mm nominal contact surface and anM3-size hole for a removable rubber/EVA
contact pad; a temporary secured pad is adequate. Its attachment is untested; pad thickness shifts the contact datum. Local support is also needed beneath the lower foot crosspiece.
No loaded limits or full swept collision range is released.

Run `node mechanical/verify-st3215-artifacts.mjs` to check existing artifact/source hashes without changing files. For fresh exports (overwrites working STLs/report), run node mechanical/check-st3215-leg.mjs for closed connected printable meshes,
print-bed bounds,proper placement rotations,clamp bore access and independently calculated70/85 mm geometry.
Recorded case clearance uses conservative rectangular envelopes at three sampled poses;
real wheel faces,connectors,cables,screw heads and rear support require dry fit. Sample checks do not release a swept or loaded range.

Manufacturer sources and immutable downloaded PDF/DXF/STEP are under
mechanical/reference/st3215; URLs recorded in decisions/st3215-3s-architecture.md.

## Small fit pack before the full leg

Print one `st3215-clamp-fit29-bottom.stl` and one
`st3215-clamp-fit29-top.stl` to try the drawing's29 mm main body band. These
are alternative clamp halves with a25.52 x29.8 mm pocket, not extra parts added
to the leg. They use the same bolt positions and external mounting stack as the
default clamps. Keep the standard35 mm clamp files as the conservative envelope
alternative until the actual grip band and ports are measured.

Use the two halves gently on an unpowered servo, checking the intended tail grip
area, connector access and shell distortion. Do not force the29 mm coupon over
32/35 mm end features. If the measured band differs, export `clamp-bottom` and
`clamp-top` with `-D case_grip_height=MEASURED_MM`; the CAD adds0.8 mm total
allowance. This is a fit starting point, not a validated clamping force.
The assembly's conservative35 mm case proxy remains unchanged; a smaller grip
pocket is not qualified by the default case collision report.

The nominal link/offset values remain70/85/85 mm. `L1` now moves the upper-link
knee seat and clamp, `L2` moves the foot, and `pitch_forward` moves the hip carrier
and pitch frame. Changes still require fresh collision/geometry checks; the
current standing/contact checks deliberately qualify only the current nominal
configuration. Fit probes using alternate dimensions are not production STLs.

After fresh exports, run `node mechanical/check-st3215-fit.mjs` for coupon bore
and independent parameter-perturbation checks. Probe outputs live in
`mechanical/st3215-fit-probes/`; do not print them as the selected leg parts.

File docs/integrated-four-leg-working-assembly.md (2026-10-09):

> Superseded MG996R/PWM design reference. Active design is ST3215 12V with3S power; see README.md,docs/st3215-leg-build.md and electronics/st3215-power-plan.md. These quantities,interfaces and mass estimates are not the current ST3215 design.

# Experimental integrated four-leg assembly

Open `mechanical/prototype-integrated-four-leg-assembly.scad` or its PNG preview.
The print/placement list is `mechanical/integrated-four-leg-print-manifest.json`:
93 pieces across21 unique STLs,12 proper servo-case poses and unchanged bench
geometry/body layout. This is working CAD, not a replacement manufacturing kit.

New part hands:

| Leg diagonal | Integrated hip | Upper/lower pitch forks |
| --- | --- | --- |
| Front-left / rear-right | Original | Mirrored |
| Front-right / rear-left | Mirrored | Original |

Other printed pieces retain their previous physical placement and hand choices.
In particular, front-left/rear-right still use mirrored knee saddles. Select
the actual supplied STL hand; a reflection matrix is not a physical placement.
All placement matrices have determinant+1 and orthonormal axes. The integrated
hip's hand names differ from the old separate carrier because its source already
contains the intended world-frame carrier geometry.

Regenerate with `node mechanical/build-integrated-four-leg-plan.mjs`. The builder
verifies baseline and new hip evidence hashes, checks all21 meshes for closed,
connected bed-sized geometry and reconciles the93-piece count. It creates the
variant mass input only if absent, preserving subsequent entered measurements.

Run `node mechanical/check-integrated-four-leg.mjs` for fresh source/placement
correspondence and nominal new-part/chassis checks. The checker covers all60
new hip/fork versus deck/mount pairs: disjoint actual-mesh bounds prove52 clear;
the eight remaining pairs are individually checked with CGAL. A combined union
export failed CGAL and was not counted. `--reuse-source-exports` is allowed only
for existing successful exports newer than every source dependency. Reports bind
input and source-export hashes. This does not qualify a continuous motion sweep,
actual servo ears/horns/leads, printing, structural strength or loaded operation.

## Variant mass recording

Use `mechanical/integrated-robot-mass-inputs.json` for slicer or measured unit
weights, actual servos/bearings/fasteners, selected power hardware and complete
measured robot weight. Fields are null until evidence exists. Run:

```text
node mechanical/check-robot-working-mass.mjs --integrated
```

The source-bound report is `mechanical/integrated-robot-mass-check.json`. The
default command still checks the old117-piece reference model unchanged.
The variant currently screens2.178kg:782g assumed prints,367g estimated
fasteners,660g servos,40g bearings and330g other allowances. Solid PETG CAD
prints total1203g; the65% material fraction is an example, not an infill setting.
Only604g remains for prints under those other assumptions, corresponding to
50.2% of solid CAD. Actual status remains NOT_MEASURED;2kg is preferred,qualified maximum TBD.

Buying quantities are in docs/purchasing-bom.md. Verify one printed/assembled
leg and actual servo duty before bulk purchases. The supported bench pack,
physical-test list and current offline firmware gates remain in place.

Current [mass policy](servo-qualified-mass.md):2kg is preferred;heavier is allowed within demonstrated servo/power duty. No physical qualification is recorded.

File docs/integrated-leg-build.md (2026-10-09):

> Superseded MG996R/PWM design reference. Active design is ST3215 12V with3S power; see README.md,docs/st3215-leg-build.md and electronics/st3215-power-plan.md. These quantities,interfaces and mass estimates are not the current ST3215 design.

# Integrated3DOF bench leg — integrated-bench-1

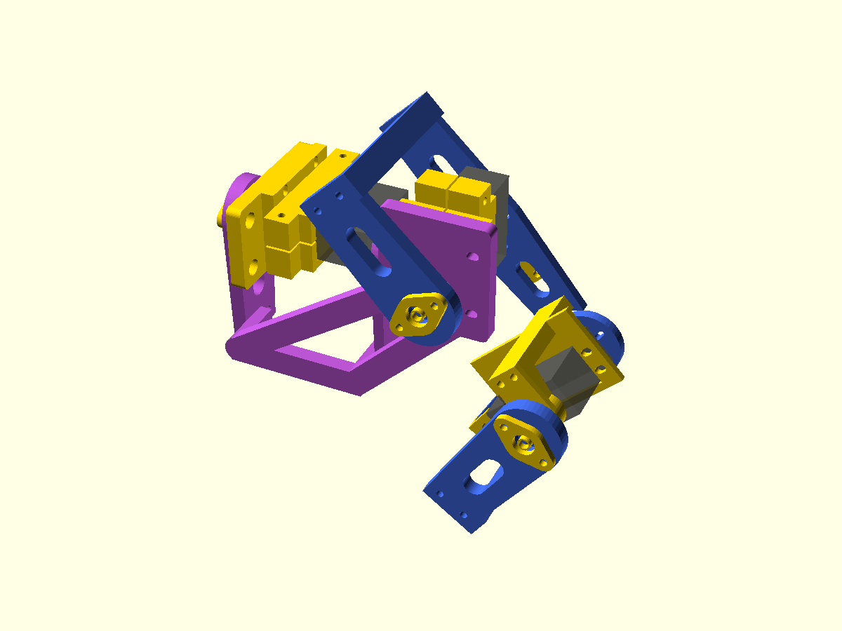
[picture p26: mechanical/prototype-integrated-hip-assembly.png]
Nominal assembly


This is an experimental print/unpowered-fit checkpoint. Use the original
integrated hip, mirrored upper/lower pitch forks and mirrored knee saddle from
this pack. The purple hip carries the blue upper fork through the J2 cradle;
the blue upper fork carries the knee servo/support, and the blue lower fork
carries the foot. Bearings, horns and fasteners are not all drawn.

## Assemble with servo power disconnected

1. Print/test the coupons and inspect all supported interfaces as described in
   [printing](integrated-leg-printing.md). Inspect one actual MG996R, supplied horn and624 bearing.
   Keep joints supported while assembling; do not force the geared servo stops.
2. Seat the J1 bearing in the rear ring of the integrated hip. Fix the separate
   retainer with two M3x16 bolts/nuts. Put the M4x35 pivot head in the fixed
   support recess before closing access, then fit the8mm inner-ring spacer,
   bearing/hip,3mm spacer, washer and locknut. Tighten only enough to retain
   the inner ring; the shields and outer ring must not be clamped by spacers.
3. Gently sandwich J1 between its cradle halves using two M3x40 bolts. Join
   the cradle, fixed support and rib-relieved bench adapter with four M3x20
   bolts. Seat the support in the adapter's relief pockets without forcing it.
   Fix the supplied J1 horn through the integrated hip's front-ring slots with
   suitable M2 through hardware and its original centre screw. Actual hole
   count and screw reach govern; do not use a guessed centre screw.
4. Fit the J2 bearing in the upper fork's rear ring and fix the second retainer
   with two M3x16 bolts. Install its recessed M4x35 pivot,8mm front spacer,
   bearing,3mm rear spacer, washer and locknut. Clamp the J2 servo in its two
   cradle halves with two M3x40 bolts. Join cradle/support to the integrated
   hip's7mm J2 mounting face with four M3x20 bolts. Fit the supplied J2 horn
   to the upper fork's front plate and secure its original centre screw.
5. Seat the knee bearing in the lower fork's rear ring; fix the third retainer
   with two M3x16 bolts. Put the knee M4x35 pivot through the knee support's
   recessed head seat, then fit the10mm front spacer, bearing/lower fork,
   3mm rear spacer, washer and locknut. Check free rotation.
6. Join upper fork, mirrored saddle and knee support with two M3x70 bolts.
   The nominal stack is5+22+36=63mm; check actual bolt reach and coaxial
   bearing alignment before tightening. Attach the knee servo through its ears
   with four M3x12 bolts/nuts. Attach its supplied horn to the lower fork and
   use its original centre screw. The fork webs replace the old bridges:
   no M3x90 bridge bolts or separate J1 arm/tab bolts are needed.
7. Attach the foot carrier behind the lower front plate with two M3x16 bolts.
   Add the assumed18x8x1mm rubber/EVA pad at its radial end. Mount the cable
   guide with one M3x16 bolt, an ordinary washer and the12mm backing washer.
   Leave slack across moving joints and keep leads clear of horn slots,
   bearings, fork webs and screw tips.
8. Mount the adapter40mm ahead of a rigid vertical board using two standoffs
   (maximum10mm OD) and M4 anchors sized for the actual board. The J1 axis
   points forward, normal to the board. Keep the board behind the moving leg;
   independently support the assembly while attaching it. CAD does not
   establish the board's strength or anchoring.
9. Gently check free motion with power disconnected. Suggested geometric
   trials are J1 -25..30deg, J2 20..55deg, J3 60..90deg; stop on any binding,
   contact or cable tension. These are sampled geometric ranges, not approved
   servo travel or loaded limits. Check actual horn/head access before loading.

All27 M3 through bolts use nuts. There are53 ordinary washers plus one backing
washer: normally one ordinary washer at each end, except the cable guide's
backing-washer end. Use washers that fit the recesses; some positions need6mm OD.
Quantities and bench-only fixtures are in [the BOM](../manufacturing/BOM.md).

Nominal angles are [0,44.0486,78.9786]deg;70/85mm links and J2 datum[85,-18,0]mm
are unchanged. The foot reference is[85,32,-120]mm in the bench frame. Measured
contact, servo zeros and usable travel remain unset. MG996R is provisional;
MG90S is unsuitable for these load-bearing joints at the current2kg requirement.

Print/support removal, servo/horn/bearing fit, unpowered assembly and gradually
loaded strength checks are all NOT_PERFORMED. Complete robot mass is unmeasured;
the four-leg screen is2.178kg, above the preferred2kg target;servo-qualified maximum remains TBD. This pack does not release
powered motion. Follow the repository's electrical commissioning procedure
before a later powered test. No extra actuator or electronics purchase is made
necessary by this mechanical checkpoint.
Current [mass policy](servo-qualified-mass.md):2kg is preferred;heavier is allowed within demonstrated servo/power duty. No physical qualification is recorded.

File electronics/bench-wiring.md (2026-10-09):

> Superseded MG996R/PWM design reference. Active design is ST3215 12V with3S power; see README.md,docs/st3215-leg-build.md and electronics/st3215-power-plan.md. These quantities,interfaces and mass estimates are not the current ST3215 design.

# Bench power and individual-servo bring-up — ELEC-001

This is a proposed test harness, not a released robot power system.
The user has an adjustable60V/5A supply. Use its low-voltage setting near5.2V
for MG996R, not60V. Its5A rating is below the7.5A three-servo capacity target:
reuse it for one-servo-first tests; verify measured demand before adding joints.
Begin with one unmounted servo and its horn removed. No battery/BEC, PCB or
full-robot power component is selected. ESP32-S3 N16R8 and Adafruit PCA9685
are owned; header mapping, PCB revision and actual PSU transient behavior
remain unverified. [Adafruit's guide](https://learn.adafruit.com/16-channel-pwm-servo-driver/hooking-it-up)
separates logic VCC from servo V+. Keep VCC/I2C at3.3V and the external servo
distribution arrangement below; ownership does not establish OE/power testing.

```mermaid
flowchart LR
  USB[USB] --> MCU[ESP32-S3]
  MCU -->|3.3V / GND / SDA4 / SCL5| PWM[PCA9685]
  PSU[Bench PSU 5.2V proposed] --> Fuse[7.5A fuse]
  Fuse --> Cut[Physical DC power cutoff]
  Cut --> Star[Rated external power star]
  Star -->|separate + and GND branches| Servos[One servo first; three later]
  Star --> Buffer[AHCT125 signal buffer]
  PWM -->|signals 0..2| Buffer
  Buffer -->|buffered signals only| Servos
  MCU -->|GPIO6 OE high = disabled| PWM
  MCU -->|same OE line| Buffer
```

All grounds join at the power star. Servo current must not flow through the
ESP32, a solderless breadboard, or unverified PCA9685 module power tracks.
Leave the module V+ servo rail unused; connect each servo's power pair directly
to the rated external distribution. Breadboard use is limited to logic.

## Proposed connections

| From | To | Check |
|---|---|---|
| ESP32 3V3 | PCA9685 VCC | I2C pull-ups must also be3.3V |
| GPIO4 / GPIO5 | SDA / SCL | Provisional ESP32-S3-DevKitC-1 mapping; verify your board |
| GPIO6 through220ohm | OE line | HIGH disables PWM;1kohm pull-up to3V3 |
| OE line | PCA OE and AHCT pins1,4,10 | Remove/conflict-check module OE pulldown; verify high with MCU disconnected |
| Switched servo rail | AHCT pin14 |5.2V nominal, never above5.3V in this harness |
| Common GND | AHCT pin7 |0.1uF ceramic directly between14/7 |
| PCA outputs0/1/2 | AHCT inputs2/5/9 |10kohm pulldown on each input |
| AHCT outputs3/6/8 | Servo signals J1/J2/J3 |220ohm series,10kohm pulldown at each signal connector |
| AHCT unused input12 | GND | Unused OE13 to its VCC; output11 unconnected |

Use AHCT, not a guessed HC substitute. Buffering avoids relying on an
unpublished servo input threshold. [TI's SN74AHCT125 datasheet](https://www.ti.com/lit/ds/symlink/sn74ahct125.pdf)
specifies its TTL-compatible input and4.5–5.5V supply. The buffer's supply is
switched with servo power so the physical cutoff removes both motor power
and the source of high-level servo signals. It is not a safety-rated stop.

Some PWM modules pull OE down. The1kohm pull-up is only a proposed default;
inspect the actual board and confirm OE exceeds0.7×3.3V before using it.
With a10kohm board pulldown the divider gives3.0V; a hard-grounded OE must
be corrected before connection. GPIO low must stay below0.8V for the buffer.
The [NXP datasheet](https://www.nxp.com/docs/en/data-sheet/PCA9685.pdf) defines
OE and configurable disabled-output states. Configure MODE2=0x04 so OE high
forces LOW; write all channels full-off before any explicit arming.

## Current and wire screen

[TowerPro's candidate data](https://towerpro.com.tw/product/mg996r/) lists4.8–6.6V,
1.4A stall and170mA no-load current. Those values do not establish the current
of an unverified delivered servo. Use2A per servo as a planning allowance:
one3-servo leg6A, plus25% capacity margin gives7.5A. An8–10A bench supply is
a proposed capacity target, not a new purchase requirement if existing equipment
can support staged testing. Do not command three servos from a smaller supply
without measurements. No twelve-servo regulator is selected.

Proposed main feed:18AWG copper, at most0.5m each direction; branches22AWG,
at most0.3m each direction. Use terminals/cutoff/connector assemblies rated
at least10A for the main path and at least2A per branch, verified from their
actual manufacturer data. The7.5A main fuse protects the feed; PSU current
limiting is still needed for initial single-servo tests. Fuse choice and wire
insulation/temperature rating must be checked against the actual harness.

`node electronics/check-bench-power.mjs` checks the wire-only drop/current
screen. Plug losses, supplied leads and temperature are excluded. Measure
voltage at the servo during motion;5.2V here leaves margin above4.8V while
remaining inside the buffer range. This is not a qualified transient design.

## First test sequence

1. Servo rail OFF; verify polarity, common ground, logic voltages and OE high.
2. MCU initializes full-off outputs with OE high; verify no servo pulses.
3. Connect one secured servo with horn removed. Start at a modest current limit,
   e.g.0.5A; if the PSU limits or voltage collapses, stop and diagnose first.
4. Enable5.2V only after confirming the actual servo's permitted voltage.
5. Explicitly arm one channel at the nominal1500us centre; expect it may move
   to an unknown centre. Initial software window1450..1550us only,50Hz.
6. Make small moves, record rail voltage/current, noise and heating. Do not
   force a stalled shaft or raise current to overcome mechanical binding.
7. Disarm and use the physical power cutoff before moving wires or fitting horns.

Removing PWM can leave a digital servo holding its last position. OE/full-off
are signal controls; the physical power cutoff is the actual power isolation.
No powered test or supply capability is claimed. The MCU GPIO proposal is based
on [Espressif's board guide](https://docs.espressif.com/projects/esp-idf/en/v4.4.3/esp32s3/hw-reference/esp32s3/user-guide-devkitc-1.html).

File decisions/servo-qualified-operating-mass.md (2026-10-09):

# Operating mass follows demonstrated servo capability

Decision date:2026-10-09. User instruction:weight may be heavier as long as the
servos can handle it. The complete2kg operating mass is now a preferred target,
not a hard ceiling. Cost/simplicity remain priorities; no actuator upgrade or
new numerical maximum is approved by this change.

Maximum acceptable operating mass stays TBD until supported leg tests and
whole-robot standing/slow-motion tests demonstrate useful torque,current,
heating and duty behavior at actual voltage,geometry and usable ranges.
Weighing a robot or comparing against stall torque does not qualify that mass.
Battery/electronics/wiring still count in complete operating mass.

The active integrated estimate remains2.178kg with provisional print/hardware
and power allowances. It is above the preferred target,not automatically
rejected. No measured masses,servo limits or physical load results are added.
Existing2kg torque cases remain reference calculations. Do not retrofit old
archived reports as qualifications for a heavier robot.

Consequences:mass reports separate target margins from a qualified limit,
which is currently null. Printed mounts may favor simpler conservative parts;
do not force weight reduction solely to meet2kg. Retain MG996R provisionally,
5.2V bench rail,70/85mm links,narrow bench commands and physical progression.

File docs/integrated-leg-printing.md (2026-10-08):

# Printing — integrated-bench-1

Use [the print list](../manufacturing/docs/print-list.md) and [the side-on coupon guide](fork-fit-coupon.md).
The23-piece assembly has15 unique STLs; five coupons are separate optional
fit checks. Start with the small side-on fork coupon before either full fork.
Use access to the K2 Pro; all supplied meshes fit within a300mm bed.

Keep each STL in its exported orientation at z=0. The integrated hip's carrier
face rests on the bed, with its output rings upright; the pitch forks stand
side-on with their web lands on the bed. Do not rotate the rings flat simply
to avoid supports: it changes the layer orientation being tested. Use the
original hip and mirrored upper/lower forks and saddle listed in this pack.

Use PLA+/PETG with your established material preset. Provisional starting
settings are0.4mm nozzle,0.2mm layers, four walls and30% infill. These are
starting process assumptions, not verified strength settings. Inspect every
slice before printing. Add a brim if needed and provide accessible supports
under the hip's raised rings, fork curved plates, horizontal bores and any
unsupported overhangs. Keep supports removable from bearing seats, horn slots
and fixing holes; inspect for sagging and trapped support after removal.
There are no claimed support-free or slicer-verified results.

Check the cradle coupon against the actual servo, bearing coupon seats
(1/2/3 dots indicate13.0/13.2/13.4mm), horn coupon and knee-ear coupon. The
new side-on coupon tests the actual fork bearing/horn geometry in its print
orientation; its connector is not a full-fork strength test. Use the same
material/layer/wall/support approach for the subsequent complete fork.

Record material, actual slicer settings, support removal, mass, horn seating,
bearing/retainer fit and bolt access. Do not glue a bearing or force a tight
servo into place before assessing fit. Reject cracks, damaged seat lips and
unremovable supports. Prototype testing, rather than further detailed stress
analysis, determines whether revisions are needed.

All prints and physical tests remain NOT_PERFORMED. The previous bench-3 pack
is archived intact as a fallback. Print and assemble one leg before considering
bulk robot purchases; complete robot2kg compliance is not established.

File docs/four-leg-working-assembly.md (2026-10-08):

# Four-leg working assembly and handed parts — MEC-158

Open `mechanical/prototype-four-leg-working-assembly.scad` for the assembly.
Its preview has the same stem. This working plan is not a manufacturing release
or a claim that the robot stands. Physical servo, horn, cable and printed fit
remain untested. The supported bench checkpoint stays in manufacturing/.

The working plan uses22 unique STLs/117 printed pieces:112 leg pieces, four
chassis mounts and one deck. No bench adapter or bench standoffs are included.
`mechanical/four-leg-working-print-manifest.json` records counts, exact STL
hashes and per-piece rigid placements. These placements are nominal only.

## Handed assignments

| Corner | J1 carrier and knee-ear saddle | Chassis mount |
| --- | --- | --- |
| Front left | New `-mirrored.stl` variants | Left |
| Front right | Original STLs | Right |
| Rear left | Original STLs | Right, rotated180deg |
| Rear right | New `-mirrored.stl` variants | Left, rotated180deg |

Only two additional leg print files are required. Each original carrier/saddle
and each mirrored carrier/saddle has quantity2. Other leg parts reuse existing
prints through rotation; cradle halves may swap roles, with8 left and8 right
halves overall. The working mount print orientation has also been corrected
to use a proper rotation for its original hand. Use its current STLs/labels.

The mirrored parts export with their existing flat z=0 face on the bed. Carrier
tabs and saddle posts remain upright. Other print guidance follows the existing
part guides; do not infer actual fit from a preview. Editable mirror source:
`mechanical/prototype-handed-parts.scad` (`part="carrier"` or `"saddle"`).

## Why the old bench view was insufficient

The J1 joint frame is right handed, but the pitch and carrier placement matrices
in the bench view have determinant-1: they reflect geometry. A reflection can
make a convincing CAD view without establishing how an actual print is fitted.
The asymmetric saddle and carrier require mirrored prints for that intended
bench orientation; this cannot be repaired by servo direction settings.

The current bench-3 checkpoint includes rib clearance and the corrected mirrored
carrier/saddle print selection. Bench-2 is archived as history. Use the current
kit for the supported leg; physical-fit flags remain false.

## Servo cases and verification

All12 MG996R case envelopes use proper rotations. For the assumed rectangular
case, reflection of its symmetric short axis can be replaced by a rigid
orientation with the same case corners and output-shaft axis. The knee case is
clocked90deg, matching the original design. No physically mirrored servo is
required. Actual ears, supplied horns and lead exit may break that simplification;
verify them before purchasing a full set or locking the mounts.

`node mechanical/build-four-leg-working-plan.mjs` regenerates the plan and view.
It checks24 axis-aligned rigid reuse orientations against actual STL vertices,
then verifies every selected mesh at its proper placement against the intended
study geometry at0.001mm coordinate resolution. The two new meshes pass closed/connected/bed checks.
`node mechanical/check-chassis-mount.mjs` checks the corrected mount exports.

`node mechanical/check-handed-correspondence.mjs` independently compares fresh
source CAD exports with the placed carrier/saddle meshes, in both directions,
within0.002mm and0.01% volume, allowing ASCII STL coordinate rounding. This avoids coplanar Boolean failures. See
the task report for the measured result. The bench manufacturing integrity check
continues to pass; integrity must not be confused with physical fit.

The root geometry and link lengths remain unchanged. Rear local pitch remains
opposite global forward; no powered body-to-leg mapping or gait is introduced.

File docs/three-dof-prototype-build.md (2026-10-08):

# Supported three-DOF bench leg — three-dof-bench-3

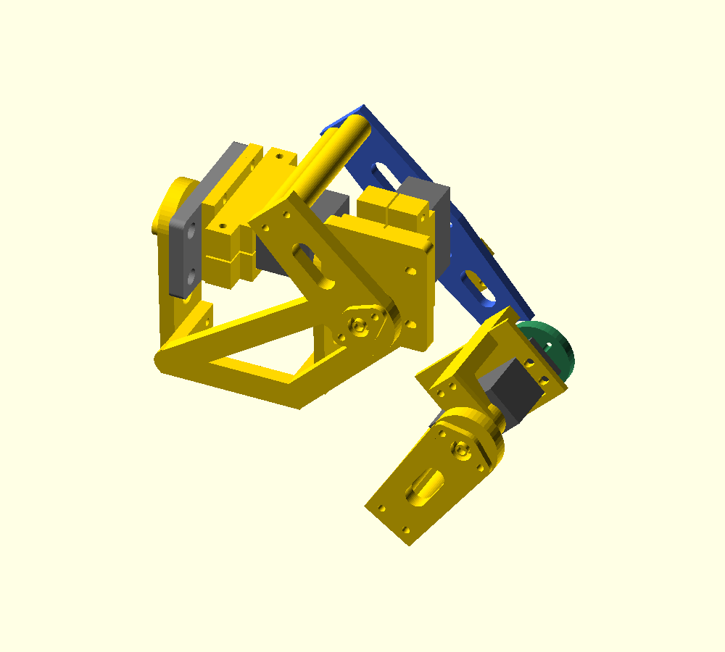
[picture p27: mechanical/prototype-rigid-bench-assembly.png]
Assembly


This prototype adds a supported J1 abduction joint to the existing J2/J3
pitch leg. It is a printing and unpowered fit checkpoint, not a walking robot.
The servo model and horn/bearing fit remain provisional.

## Print and buy

Use the three-DOF print manifest and hardware BOM, not the sum of earlier kits.
Reuse current pitch-leg prints except the saddle hand specified below. Add one left/right cradle pair, fixed
support, front arm, rear arm, retainer, 8mm front spacer, 3mm rear spacer,
and the new J1 carrier. The existing bench adapter moves from J2 to J1;
there is only one bench adapter. Do not print an extra J1 bridge: the carrier
ties the front and rear fork arms together.

Use the current rib-relieved adapter STL from the corrected bench-3 checkpoint.
Its pockets face the passive support and provide0.2mm clearance around the ribs.
Check that the support seats freely before tightening; the older adapter had a
CAD clash. Bolt slots, anchors and hardware quantities are unchanged.

Use `prototype-j1-carrier-mirrored.stl` and `prototype-upper-leg-saddle-mirrored.stl`
for this bench orientation. They replace the two original print files; do not
print both hands for one bench leg. The original saddle remains valid for the
standalone two-DOF frame, but the three-DOF bench uses this mirrored selection.
Actual part placement is in `prototype-rigid-bench-assembly.scad`; the older
three-DOF source is a reflected geometric reference, not a physical print plan.
The new view shows prints and case envelopes; bearings, horns and fasteners
follow the assembly instructions below and are not fully drawn in that view.

Print fit coupons first. Print the carrier flat as exported, with its tabs
upright. Start with PLA+/PETG, 0.4mm nozzle, 0.2mm layers, four walls and 30%
infill. Inspect the 3.5mm horizontal tab holes and use a brim if needed.
These process settings are assumptions; inspect the sliced part before printing.

## Assembly

1. Build the two-DOF pitch leg using its guide, omitting the bench adapter.
   Use four M3x20 bolts through its cradle, support and new 7mm carrier face.
2. Build the J1 bearing stack: 624 bearing in the rear arm, retainer with two
   M3x16 bolts, M4x35 pivot in the fixed support, 8mm front spacer, bearing,
   3mm rear spacer, washer and locking nut. Tighten only enough to retain
   the bearing inner ring; verify free rotation and no shield contact.
3. Orient both J1 fork arms downward, 90 degrees from their original bench
   orientation. Attach their distal two holes to the carrier end tabs using
   four M3x20 bolts with nuts and washers. The carrier tabs have 14mm hole
   spacing, at 21mm and 35mm above the carrier print bed. Fit all four bolts
   loosely before tightening. Do not force misaligned arms into position.
4. Clamp the J1 servo with two M3x40 bolts. Attach its cradle, fixed support
   and the relocated bench adapter with four M3x20 bolts. Assemble the
   recessed M4 pivot before closing access with the cradle.
5. Attach the supplied J1 horn to the front arm with matching M2 through
   bolts and its original centre screw. Horn holes/count/length are actual
   fit checks. Do not substitute a guessed screw for the centre screw.
6. Mount the J1 adapter 40mm ahead of a rigid vertical board using two
   maximum-10mm-OD standoffs and M4 anchors selected for the actual board.
   J1's axis points forward, normal to the board. The modeled bracket is
   not the board or a certification of its strength. Independently support
   the leg while assembling and ensure the board lies behind moving parts.
7. Route the J1 lead on the fixed side. Leave a slack loop from the moving
   pitch leg around J1; use soft ties on the carrier without trapping leads
   against horn slots, bearings or end tabs.
8. Gently check all joints by hand, staying away from geared servo stops.
   Suggested geometric trial poses: J1 -25..30 degrees, J2 20..55 degrees,
   J3 60..90 degrees. Samples do not qualify every combination or real
   cables/fasteners. Reduce travel immediately if anything touches or binds.

## Frame and limits

Body axes are forward +x, left +y and up +z. This reference-left bench leg
has J1 about +x. J2's floor datum is [85,-18,0]mm in the J1 frame;
the nominal foot plane is +32mm outward and the contact is 120mm below J1
at the retained standing pose. Positive J1 moves the foot outward.
The 85mm forward offset is a deliberately generous bench carrier; chassis
mounting and four-leg symmetry remain a later integration decision.
The original 25mm-offset skeleton remains historical reference geometry.

The 2kg/three-support-leg J1 screen uses 6.54N ground force and 0.12Nm
moving-part allowance. Stall torque is not continuous torque. No powered
loading is released. Measure supply voltage/current, polarity and actual
servo behaviour before a later powered trial; never power servos through
the ESP32 board. Final robot mass and loaded range are unresolved.

Next physical milestone: print the coupons, verify an actual servo and bearing,
then assemble this leg unpowered. Electronics/chassis work has not begun.

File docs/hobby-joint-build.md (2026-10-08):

# Supported bench-joint print kit

MEC-123–132 produces one supported servo joint for cheap mechanical testing.
It is **not yet a complete 3-DOF leg**. The oversized kit tests case grip,
horn mounting and rear-bearing alignment before making integrated leg mounts.

## Print the fit samples first

Use the existing cradle coupon, new horn coupon and bearing coupon before
printing the full kit. Verify the actual servo body, output-shaft position,
horn face height, available horn holes, cable exit and mounting-ear clearance.
The assumed shaft is 10 mm from the short body end and the horn face is
50 mm above the cradle base. Adjust `shaft_x`/`horn_z` in the common source
and layout JSON if measurements differ; recompile affected parts.

Bearing coupon dots identify seats: one =13.0 mm, two =13.2 mm, three =13.4 mm.
Choose a seat that accepts the actual 624 bearing without force and retains it
without obvious radial movement. Change `seat_d` and layout JSON to match.
Do not hammer the bearing into a printed arm. The 4 x13 x5 mm bearing boundary
is from [SKF's public product data](https://www.skf.com/ro/products/rolling-bearings/ball-bearings/deep-groove-ball-bearings/productid-624-2RS1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).
Use a commodity bearing; no brand or purchase has been locked.

## Parts for one joint

| Item | Quantity | Notes |
| --- | ---: | --- |
| MG996R-sized positional servo with supplied horn/centre screw | 1 | Packaging candidate; verify actual unit |
| Cradle left/right | 1 each | Existing MEC-122 STLs |
| Support, front arm, rear arm, bridge, retainer | 1 each | New STL parts |
| Front spacer / rear spacer | 1 each | Nominal8 mm /3 mm; metal substitutes permitted |
| 624 bearing, 4 x13 x5 mm | 1 | Actual fit checked with coupon |
| M3 x40 bolts with washers/nuts | 2 | Cradle clamp |
| M3 x16 bolts with washers/nuts | 6 | Four base mounts, two bearing-retainer mounts |
| M3 x90 bolts with washers/nuts | 2 | Or cut M3 threaded rods to suit; bridge stack78.2 mm |
| M4 x35 socket-head screw, washer and locking nut | 1 | Retains stationary bearing inner ring; verify head fits7.5 x4.5 mm pocket |
| M2 horn through bolts with nuts | 2–4 | Start with10 mm; actual horn thickness/access sets length |

No printed spline or structural printed threads. Use the supplied servo centre
screw for its original horn. Do not substitute an M2 screw for an unknown spline
thread. Horn nuts and tips must clear the case during hand rotation.

## Printing

All manifest STLs sit on z=0. PLA+ or PETG, 0.4 mm nozzle, 0.2 mm layers,
four walls and about30% infill are starting settings. Arms print flat;
the bridge prints upright with a brim. Check adhesion on its tall columns.
Clear horizontal cradle holes carefully with a drill if needed. The support's
recessed head pocket has a short7.5 mm bridge: inspect the roof in the slicer.
Small spacers need thin-wall slicing; their0.75 mm wall is intentional. Common
metal M4 spacers with suitable inner-ring contact are preferable if these fail
to print cleanly. The assembly STL is a reference scene, not a print part.

## Unpowered assembly sequence

1. Fit the actual bearing into the rear arm and bolt on its retaining plate.
   The plate contacts the outer ring; the central10 mm opening clears the
   inner-ring spacer and M4 washer. Use two M3 x16 through bolts and nuts.
2. Insert the M4 bolt into the support's recessed head pocket while it is
   accessible. Put the8 mm front spacer, rear-arm bearing,3 mm rear spacer,
   washer and locking nut onto the bolt. The spacers touch only the inner
   ring. Tighten lightly enough to retain the stack, then check smooth rotation.
   If the shield or rotating arm rubs a spacer/washer, correct that contact.
3. Join rear arm,66.2 mm bridge and front arm with the two long M3 bolts.
   Their nominal centre pitch is14 mm. Keep both arms parallel.
4. Clamp the servo in the cradle gently. Mount the cradle onto the support
   with four M3 x16 bolts through the base slots. This closes access to the
   recessed M4 head; assemble its bearing stack first.
5. Attach the supplied horn to the front arm through matching radial slots,
   then fit it to the servo using the original centre screw. The10 mm centre
   opening provides driver access. Actual horn geometry determines screw
   count and length; the printed coupon checks this cheaply.
6. Gently move the unpowered assembly through a small useful arc, staying
   away from servo end stops. Check binding, case slip, bearing retention,
   exposed fasteners and cable clearance. Do not force a geared servo.
   If alignment binds, adjust the case position/datum rather than loading it.

Powered loading is a later physical task after the actual supply, polarity,
voltage and current capacity have been checked. Servos must never be powered
through an ESP32 board. No powered-test results are claimed here.

## Checks and limits

Run `powershell -File mechanical/check-hobby-joint.ps1`. It verifies nine new
closed connected STL meshes, print-bed placement, common-source/layout values,
the nominal stack and conservative local rotating clearance. Minimum modeled
radial margin is2.67 mm after0.8 mm allowance. This excludes actual horns,
cables, fastener envelopes and downstream links; hand fit remains essential.
The nominal assembly preview was visually inspected.

Printed solid volume corresponds to83.5 g using assumed PETG density1.27 g/cm3.
A rough65% material fraction gives54.3 g printed plus55 g servo per joint;
twelve such copies total about1.31 kg before bearings, fasteners, battery,
chassis and electronics. **Do not replicate this bench kit twelve times for
the robot.** Slicer mass and weighed prints supersede this rough estimate.
The next leg design needs lighter integrated mounts, retaining the passive
support concept. The1.2 kg target is unchanged and is not currently met by
this replication scenario.

The existing NZ$25–35 servo cap still multiplies toNZ$300–420 for twelve;
the NZ$680–800 whole-project allocation is a planning cap, not verified retail
pricing. Buy/test one positional servo and one bearing first, rather than
committing to twelve. No purchasing or supplier contact occurred.

Next suggested stage-4 task: create one70 mm upper-leg mount joining the hip
fork to the knee servo with an integrated lighter holder. Use fit-coupon
results if available; keep unmeasured interfaces explicitly provisional.
No following major stage was started in this batch.

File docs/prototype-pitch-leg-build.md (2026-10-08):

# Supported two-DOF pitch-leg print kit — MEC-134–143

This kit adds the knee passive support and85mm lower link to the70mm upper
link. Both pitch joints have rear bearing support. J1 abduction is still absent;
this is not yet a3DOF leg. No physical assembly or powered tests were performed.

## Print and fit

Use mechanical/pitch-leg-print-manifest.json for part quantities. Most parts
are shared with the earlier kits; do not print the superseded hip front arm.
Print the original cradle, horn and bearing coupons plus the knee-ear coupon
first. Servo case, shaft offset, ear height/hole pitch, horn face and bearing
fit remain assumptions until checked on one actual unit.

Print each STL as exported at z=0, with0.4mm nozzle,0.2mm layers and PLA+/PETG.
Use four walls and about30% infill as starting settings. Links print flat;
bridges upright with brims. The knee support prints on its base without added
supports. Check small inner-ring spacers for clean walls; metal equivalents
are acceptable if printed spacers bind or deform. Clear small horizontal holes
carefully if needed. Slicer/print inspection replaces assumed process quality.

## Assembly changes

1. Assemble the supported hip using the earlier guide, with the upper plate
   replacing its short front arm. Hip bridge is on the opposite side; rear
   arm rotates180deg in its plane. Reuse its8mm front spacer and3mm rear spacer.
2. Seat the knee bearing in the second existing rear arm and add its retainer.
   Insert the knee M4 pivot through the new support's head recess before the
   support is attached. Add the10mm front spacer, bearing,3mm rear spacer,
   washer and locking nut. Tighten lightly; spacers touch only the inner ring.
3. Fit the support underneath the knee saddle. Replace its two previous
   M3x40 joining bolts with M3x70: upper plate5+saddle22+support36=63mm stack.
   Use washers/nuts. Check bearing coaxial alignment and actual screw reach.
4. Attach the knee servo by its ears, then mount the lower front link on the
   supplied horn with through bolts and the original centre screw. Use the
   second66.2mm bridge and twoM3x90 bolts to join front/rear arms. Hand motion
   must remain free without servo-case slip or shield/washer contact.
5. Attach the foot carrier behind the lower front plate with twoM3x16 bolts.
   Its end wall remains beyond the link tip. An18x8x1mm rubber/EVA piece on
   that radial end gives85mm knee/contact reference. Different thickness or
   compression changes actual contact and must be measured.
6. Clamp the cable guide onto the negative upper-plate window using oneM3x16
   bolt, ordinary washer above and12mm OD backing washer below. Mounting
   hole is x=-30.5mm; guide origin=-24.5mm. Leave slack and tie gently. Keep
   wires away from rotating horns, bridge columns and fastener tips.

Follow docs/purchasing-bom.md for quantities; old hardware lists are replaced,
not added. Actual horn screw length and cable routing remain fit checks.

## Bench fixture

The revised7mm adapter is below the fixed hip support, top z=-3mm and back
z=-10mm. Its22mm opening clears the pivot boss. The original5mm broad flat
plate was rejected during assembly review because it occupied the boss/sweep
space; final source/export uses the compact negative-x anchor layout.

Use fourM3x20 cradle/support/adapter bolts, with heads behind the adapter and
nuts on the cradle flange. Small6mm OD washers aid access. Head depth must
clear the rear arm. Mount the adapter40mm ahead of a rigid vertical board via
two maximum10mm OD standoffs and M4 anchors at x=-35,y=+/-12mm in adapter
coordinates. Example M4x70 suits a12mm board; choose length for actual material.
Heads seat in recessed pockets; washers are on the board/nut side. The board
is behind the rear-arm space. The CAD does not supply a bench or certify its
anchoring: confirm it is rigid and all parts clear before loading.

The source uses local z along the pitch shafts. For standing orientation,
local x points upward, local y backward and local z laterally; do not put the
rear fork directly against a solid tabletop or mounting wall.

## Verification and2kg limits

`powershell -File mechanical/check-prototype-pitch-leg.ps1` checks six new
connected closed STL meshes,70/85mm nominal closure, sampled bridge/fixture
clearance and saved exact front-plate probes. Front-arm/upper-plate modeled
intersections are empty at20,79 and90deg knee flexion. The bridge is checked
at1deg samples over20–90deg, minimum conservative margin1.16mm after0.8mm
allowance. Actual screws, horns, cables, limits and pad compliance are not
qualified by those checks. The nominal assembly render was visually reviewed.

User changed the maximum COMPLETE robot mass to2kg on2026-10-08. The new
three-support-leg static screen uses6.54N per leg,49mm knee lever and0.10Nm
moving-parts allowance: about0.42Nm versus0.92Nm published4.8V stall torque.
This justifies a bent-pose prototype trial, not continuous operation. A full
horizontal155mm leg exceeds that stall comparison: do not treat desired joint
ranges as approved loaded motion. Historical1.2kg reports were not rescaled.

Printed pitch-leg solid mass is about156g, excluding the bench adapter; actual
infill and measured mass supersede it. Two servos add110g. Final3DOF/four-leg
mass, J1 torque and electrical power capacity remain unverified. Budget limits
are unchanged. Never power servos through the ESP32 board.

Only unpowered fit/motion checks are ready for the user. Powered work requires
the actual supply voltage/current, polarity and suitable PWM source to be
checked first. No measurement or acceptance is claimed by these instructions.

Next suggested stage4 task: design the J1 abduction carrier connecting this
pitch-leg module to the third servo, with the minimum spacing/torque check.
It is not started in this batch. No chassis/electronics stage started.

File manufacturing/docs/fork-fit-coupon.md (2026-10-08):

# Side-on fork fit coupon

Print `../coupons/prototype-fork-fit-coupon.stl` on the K2 Pro in its supplied
orientation. It is36 x78.2 x32mm. The long connector sits on the bed; do not
lay either round interface plate flat, because this test concerns the new
side-on fork printing orientation.

The coupon contains the actual upper fork's horn plate and rear bearing seat,
cropped around the interfaces and joined by a smaller coupon-only connector.
The seat is13.2mm diameter x5.2mm deep for a nominal13 x5mm624 bearing. Retainer
holes are3.5mm diameter on22mm centres. Horn slots and centre opening retain
the fork geometry. The connector does not reproduce the full fork's stiffness.

Use your normal PETG material preset. As a provisional starting profile, use
0.2mm layers and four walls; use the same layer/material/wall profile later
when printing the forks. Inspect the slicer preview for local supports under
the curved plates and horizontal bores. Keep support interfaces accessible for
removal and add a brim if needed. Record actual support settings rather than
assuming this is a support-free print. The CAD estimate is17.6g solid PETG;
infill, support and brim change filament use. No slicing or printing was performed.

1. Inspect the slicer layer preview, print, and remove supports without enlarging
   the bores. Check for sagged slots, cracks or damaged seat lips.
2. Once available, insert a624 bearing from the outer rear face. It should seat
   flat without splitting the print or needing destructive force. Record any
   looseness; do not glue it before assessing fit.
3. Fit the existing `hobby-joint-retainer.stl` with the existing specifiedM3
   fixings. Verify hole alignment and access. Check that the bearing is retained
   and that the centre opening clears the intended pivot/spacer stack.
4. Once the actual MG996R horn is available, check the horn plate's centre and
   fixing slots, fastener/head access and horn seating. The guessed horn pattern
   is not qualified by a successful bearing test.
5. Record material, settings, support removal, mass, bearing/retainer fit and
   actual horn fit before printing a complete experimental fork. Revise fit
   dimensions from this evidence only if needed.

Current results: print/support removal **NOT_PERFORMED**; bearing/retainer fit
**NOT_PERFORMED**; horn fit **NOT_PERFORMED**. Bearing, servo/horn and fixing
hardware are already on the first-leg buying list; no extra purchase is added.
The coupon does not qualify loaded strength. Full-fork and gradually loaded
assembled-leg tests remain separate, and the bench-3 fallback remains archived intact.

Regenerate the STL with the project-local OpenSCAD, then run
`node mechanical/check-fork-fit-coupon.mjs`. The check independently verifies
closed/connected surfaces, bed bounds and27 clear/blocked mesh rays through
the actual fixing slots, seat wall/floor and centre openings. Its report is
`mechanical/fork-fit-coupon-check.json`.

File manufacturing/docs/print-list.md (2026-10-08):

# Print list — integrated-bench-1

15 unique assembly STLs/23 pieces; five optional fit coupons. Print coupons before full parts.

| File | Qty | Use |
| --- | ---: | --- |
| [hobby-servo-cradle-left.stl](../stl/hobby-servo-cradle-left.stl) | 2 | Leg |
| [hobby-servo-cradle-right.stl](../stl/hobby-servo-cradle-right.stl) | 2 | Leg |
| [hobby-joint-support.stl](../stl/hobby-joint-support.stl) | 2 | Leg |
| [hobby-joint-front-spacer.stl](../stl/hobby-joint-front-spacer.stl) | 2 | Leg |
| [hobby-joint-rear-spacer.stl](../stl/hobby-joint-rear-spacer.stl) | 3 | Leg |
| [hobby-joint-retainer.stl](../stl/hobby-joint-retainer.stl) | 3 | Leg |
| [prototype-upper-leg-saddle-mirrored.stl](../stl/prototype-upper-leg-saddle-mirrored.stl) | 1 | Leg |
| [prototype-cable-guide.stl](../stl/prototype-cable-guide.stl) | 1 | Leg |
| [prototype-knee-support.stl](../stl/prototype-knee-support.stl) | 1 | Leg |
| [prototype-knee-spacer.stl](../stl/prototype-knee-spacer.stl) | 1 | Leg |
| [prototype-foot.stl](../stl/prototype-foot.stl) | 1 | Leg |
| [prototype-bench-base.stl](../stl/prototype-bench-base.stl) | 1 | Bench adapter |
| [prototype-pitch-fork-upper-mirrored.stl](../stl/prototype-pitch-fork-upper-mirrored.stl) | 1 | Leg |
| [prototype-pitch-fork-lower-mirrored.stl](../stl/prototype-pitch-fork-lower-mirrored.stl) | 1 | Leg |
| [prototype-integrated-hip.stl](../stl/prototype-integrated-hip.stl) | 1 | Leg |
| [hobby-servo-cradle-coupon.stl](../coupons/hobby-servo-cradle-coupon.stl) | 1 | Fit coupon |
| [hobby-joint-bearing-coupon.stl](../coupons/hobby-joint-bearing-coupon.stl) | 1 | Fit coupon |
| [hobby-joint-horn-coupon.stl](../coupons/hobby-joint-horn-coupon.stl) | 1 | Fit coupon |
| [prototype-upper-leg-ear-coupon.stl](../coupons/prototype-upper-leg-ear-coupon.stl) | 1 | Fit coupon |
| [prototype-fork-fit-coupon.stl](../coupons/prototype-fork-fit-coupon.stl) | 1 | Fit coupon |

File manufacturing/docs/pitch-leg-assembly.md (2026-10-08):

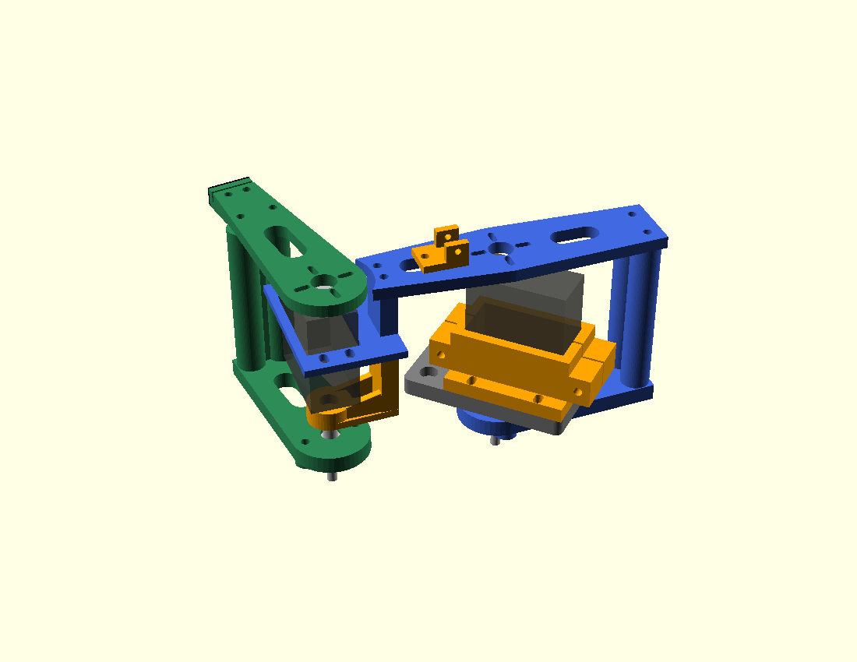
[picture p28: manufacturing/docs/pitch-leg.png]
Current assembly


# Supported two-DOF pitch-leg print kit — MEC-134–143

This kit adds the knee passive support and85mm lower link to the70mm upper
link. Both pitch joints have rear bearing support. J1 abduction is still absent;
this is not yet a3DOF leg. No physical assembly or powered tests were performed.

## Print and fit

Use ../release-manifest.json for part quantities. Most parts
are shared with the earlier kits; do not print the superseded hip front arm.
Print the original cradle, horn and bearing coupons plus the knee-ear coupon
first. Servo case, shaft offset, ear height/hole pitch, horn face and bearing
fit remain assumptions until checked on one actual unit.

Print each STL as exported at z=0, with0.4mm nozzle,0.2mm layers and PLA+/PETG.
Use four walls and about30% infill as starting settings. Links print flat;
bridges upright with brims. The knee support prints on its base without added
supports. Check small inner-ring spacers for clean walls; metal equivalents
are acceptable if printed spacers bind or deform. Clear small horizontal holes
carefully if needed. Slicer/print inspection replaces assumed process quality.

## Assembly sequence

1. Fit a 624 bearing into the hip rear arm and secure its retainer with two
   M3x16 bolts/nuts. Insert the M4x35 pivot into the fixed support recess,
   then fit the 8mm spacer, bearing/rear arm, 3mm spacer, washer and locking
   nut. Spacers contact only the inner ring; check smooth rotation.
   Join the rear arm and upper plate with the bridge and two M3x90 bolts.
   Clamp the servo gently between cradle halves using two M3x40 bolts.
   Mount cradle/support/bench adapter with four M3x20 bolts; assemble the
   recessed pivot first. Attach the supplied horn to the upper plate through
   its slots, then use the original servo centre screw. Check screw tips,
   actual horn geometry and case alignment. The upper plate is
   replacing its short front arm. Hip bridge is on the opposite side; rear
   arm rotates180deg in its plane. Reuse its8mm front spacer and3mm rear spacer.
2. Seat the knee bearing in the second existing rear arm and add its retainer.
   Insert the knee M4 pivot through the new support's head recess before the
   support is attached. Add the10mm front spacer, bearing,3mm rear spacer,
   washer and locking nut. Tighten lightly; spacers touch only the inner ring.
3. Fit the support underneath the knee saddle. Replace its two previous
   M3x40 joining bolts with M3x70: upper plate5+saddle22+support36=63mm stack.
   Use washers/nuts. Check bearing coaxial alignment and actual screw reach.
4. Attach the knee servo by its ears using four M3x12 bolts/nuts, then mount the lower front link on the
   supplied horn with through bolts and the original centre screw. Use the
   second66.2mm bridge and twoM3x90 bolts to join front/rear arms. Hand motion
   must remain free without servo-case slip or shield/washer contact.
5. Attach the foot carrier behind the lower front plate with twoM3x16 bolts.
   Its end wall remains beyond the link tip. An18x8x1mm rubber/EVA piece on
   that radial end gives85mm knee/contact reference. Different thickness or
   compression changes actual contact and must be measured.
6. Clamp the cable guide onto the negative upper-plate window using oneM3x16
   bolt, ordinary washer above and12mm OD backing washer below. Mounting
   hole is x=-30.5mm; guide origin=-24.5mm. Leave slack and tie gently. Keep
   wires away from rotating horns, bridge columns and fastener tips.

Follow ../BOM.md for quantities; old hardware lists are replaced,
not added. Actual horn screw length and cable routing remain fit checks.

## Bench fixture

The revised7mm adapter is below the fixed hip support, top z=-3mm and back
z=-10mm. Its22mm opening clears the pivot boss. The original5mm broad flat
plate was rejected during assembly review because it occupied the boss/sweep
space; final source/export uses the compact negative-x anchor layout.

Use fourM3x20 cradle/support/adapter bolts, with heads behind the adapter and
nuts on the cradle flange. Small6mm OD washers aid access. Head depth must
clear the rear arm. Mount the adapter40mm ahead of a rigid vertical board via
two maximum10mm OD standoffs and M4 anchors at x=-35,y=+/-12mm in adapter
coordinates. Example M4x70 suits a12mm board; choose length for actual material.
Heads seat in recessed pockets; washers are on the board/nut side. The board
is behind the rear-arm space. The CAD does not supply a bench or certify its
anchoring: confirm it is rigid and all parts clear before loading.

The source uses local z along the pitch shafts. For standing orientation,
local x points upward, local y backward and local z laterally; do not put the
rear fork directly against a solid tabletop or mounting wall.

## Verification and2kg limits

The recorded source verification in ../validation.json checks six new
connected closed STL meshes,70/85mm nominal closure, sampled bridge/fixture
clearance and saved exact front-plate probes. Front-arm/upper-plate modeled
intersections are empty at20,79 and90deg knee flexion. The bridge is checked
at1deg samples over20–90deg, minimum conservative margin1.16mm after0.8mm
allowance. Actual screws, horns, cables, limits and pad compliance are not
qualified by those checks. The nominal assembly render was visually reviewed.

User changed the maximum COMPLETE robot mass to2kg on2026-10-08. The new
three-support-leg static screen uses6.54N per leg,49mm knee lever and0.10Nm
moving-parts allowance: about0.42Nm versus0.92Nm published4.8V stall torque.
This justifies a bent-pose prototype trial, not continuous operation. A full
horizontal155mm leg exceeds that stall comparison: do not treat desired joint
ranges as approved loaded motion. Historical1.2kg reports were not rescaled.

Printed pitch-leg solid mass is about156g, excluding the bench adapter; actual
infill and measured mass supersede it. Two servos add110g. Final3DOF/four-leg
mass, J1 torque and electrical power capacity remain unverified. Budget limits
are unchanged. Never power servos through the ESP32 board.

Only unpowered fit/motion checks are ready for the user. Powered work requires
the actual supply voltage/current, polarity and suitable PWM source to be
checked first. No measurement or acceptance is claimed by these instructions.

Not included in this package: the J1 abduction carrier connecting this
pitch-leg module to the third servo, with the minimum spacing/torque check.
It is not started in this batch. No chassis/electronics stage started.

Fit coupon IDs: cradle coupon, bearing coupon (1/2/3 dots = 13.0/13.2/13.4mm seats), horn coupon and upper-leg ear coupon. Files are in ../coupons; print one each before the full kit. The current rear-arm bearing seat is 13.2mm. Failed fit requires a design revision and regenerated pack.

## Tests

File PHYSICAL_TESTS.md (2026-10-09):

# Physical tests pending — ST3215 /3S
No listed test has been performed. Current CAD is provisional.

1. Check one **12V** ST3215,its front/rear wheels and supplied screws. Measure
   case,shaft offsets,wheel faces and mounting pitch. Verify rear wheel rotates
   as an independent support,not a stationary case attachment.
2. Print one clamp pair/spacer: start with the29 mm fit coupons only if the
   measured grip band suits them; otherwise export the measured grip height.
   Measure front/rear wheel faces separately and set each spacer. Check gentle grip,case shape,connector access,
   spacers and wheel thread engagement. Do not force clamp or preload shaft.
3. Dry assemble complete secured bench leg. Check both wheel attachments,
   bolt/tool access,cables and low-angle travel before powered testing. Existing
   MG996R manufacturing pack/fit records do not apply. For the new chassis,
   verify hip reliefs, sixteen fixture bolts, tray fasteners/straps and removable
   deck access; confirm real boards/USB/leads fit before repeating four legs.
4. Read actual battery label:3S conventionalLiPo,capacity,C/current rating,
   dimensions,mass,connector. Inspect condition and individual cell voltages.
   Check charger,main fuse,disconnect and distribution ratings before use.
5. Follow docs/st3215-feedback-bench.md using firmware/st3215 (compiled only).
   One unmounted servo only:verified adapter wiring,12.0V current-limited PSU,
   horn removed initially. Read position/voltage; verify startup torque state,
   ID uniqueness,limits,communication-loss behavior and explicit torque-off.
6. Configure one servo ID at a time,then map joints1..12. Confirm position readback
   against physical angle; do not equate4096counts/revolution with joint accuracy.
7. Calibrate direction,centre and narrow safe ranges on supported leg. Validate
   every joint separately before simultaneous commands. Old PWM firmware is
   incompatible and must not be flashed to control these actuators.
8. Record individual and leg current,servo-bus voltage sag/transients,holding,
   horn slip,gear behavior and heating during representative duty.5A PSU supports
   staged trials,not the8.1A three-servo stall sum. Never deliberately stall.
9. Increase supported foot load gradually near intended stance. Three-leg
   representative load = actual robot mass x9.81 /3. Measure complete mass
   including60 Wh battery; old2.178 kg MG996R estimate is obsolete. Qualify actual
   standing/slow-motion duty before accepting heavier operating mass.
10. Before untethered operation,verify logic/servo power sequencing,individual
    cell alarm,low-battery controlled stop and manual disconnect. Test safe
    shutdown while robot is supported; removing torque can cause collapse.

Available:user-reported Creality K2 Pro,ESP32-S3 N16R8,PCA9685,multimeter,
load cells and60V/5A supply. Do not exceed12.6V servo input; initial12.0V.
Battery voltage diagnostic remains manual; automatic cutoff and off-state sense
protection have not been implemented.

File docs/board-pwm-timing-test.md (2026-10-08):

# Board-only PWM timing check — ELEC-003

This can be prepared using the owned ESP32-S3 N16R8 and Adafruit PCA9685,
without servos, a battery or the bench supply. No physical test has been run.
Verify the actual board labels and3.3V rail with the multimeter first.

## Wiring with power disconnected

| ESP32 board | Adafruit PCA9685 |
|---|---|
|3V3 | VCC, logic only |
|GND | GND |
|GPIO4 | SDA |
|GPIO5 | SCL |
|GPIO6 through220ohm | OE, with1kohm pull-up from OE to3V3 |
|GPIO7, input only | PWM/signal pin of channel15 |

GPIOs are provisional DevKitC mappings: use GPIO numbers, not guessed header
positions. Leave V+, the servo terminal block, all servo connectors and the
5V signal buffer disconnected for this check. Channel15's signal pin must
be distinguished from its V+ and GND pins. Never loop5V buffer output into GPIO7.

[Adafruit's pinout guide](https://learn.adafruit.com/16-channel-pwm-servo-driver/pinouts)
states that VCC supplies logic/pullups/output voltage, OE is pulled low by
default, and V+ is separate. The pull-up establishes disabled startup;
verify it against the actual PCB revision. Existing bench passives/jumpers
cover this connection; no new controller, PWM module or scope purchase.

## Procedure after reviewing/uploading the firmware yourself

Use the UART/programming USB connection appropriate to the actual dev board.
Open a115200baud serial monitor; do not run the automatic bench console at
the same time. Alternatively use the supervised console below. Confirm DISARMED
and no connected servo or servo power, then type:

```text
timing rail-off no-servos
```

The words acknowledge your setup; they are not a voltage sensor. The command
is rejected while armed/faulted. It clears all16 channels, then temporarily
enables only channel15 at nominal1500us/50Hz. All actuator channels stay full-off.
After measurement it raises OE before cleanup writes and clears all channels.
Bus/configuration/cleanup failures latch FAULT; missing or out-of-range timing
is reported without inventing a measurement. No automatic retry or oscillator
correction is performed.

Three high/low pairs are measured using the installed Arduino-ESP32 pulseIn
implementation. Each call has a50ms timeout, at most300ms total acquisition
wait. The reported period is high+low from periodic waveform portions, not
a simultaneous two-edge capture. Each pair must have1400..1600us high time
and19000..21000us summed period to pass. These are coarse bring-up screens,
not servo calibration tolerances or a precision scope replacement.

Record actual high_us/period_us in electronics/bench-commissioning.json optional
PWM fields, together with date/operator and setup observations. This verifies
logic timing only: it does not measure amplitude,5V buffer behavior, motor
current, servo response, physical fit or loaded duty. If timing fails, check
logic voltage, channel/pin wiring, OE and configured oscillator before motion.

## Supervised console capture — FW-009

After the same wiring checks, use your verified explicit COM port:

```powershell
& C:\Users\Kyle\.platformio\penv\Scripts\python.exe firmware/bench_console.py --port COM5 --timing-log electronics/board-timing-first.jsonl
```

The log path must be new; an existing file is never overwritten. The console
still never arms automatically. While DISARMED, type `timing rail-off no-servos`.
It rechecks state, accepts exactly one diagnostic line plus its cleanup status,
and uses a1second diagnostic deadline. The usual0.35second state/motion reply
deadline stays unchanged. The extra time allows acquisition, I2C cleanup and
serial delivery; it does not extend an armed keepalive.

Each complete validated reply is printed as JSON and optionally logged with a
UTC capture timestamp. PASS requires three samples and the existing timing
screens. NO_SIGNAL and OUT_OF_RANGE retain the reported failure values without
automatic retry. Bus/configuration/cleanup faults retain a complete fault capture
and stop the session. Malformed, incomplete or timed-out replies stop without
publishing a timing capture. No automatic reconnect/reset occurs.

Rail-off and disconnected-servos fields are operator acknowledgements. The
voltage-measured field remains null; a timing log does not update commissioning
voltage records or authorize servo motion. All current physical results remain
NOT_PERFORMED. Fake-transport test logs exist only under ignored test-output.

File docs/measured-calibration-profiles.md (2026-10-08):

# First-leg measured profiles — offline only

`firmware/calibration_profiles.py` validates a completed copy of
`firmware/joint-calibration.json`, previews angle-to-pulse mappings and optionally
exports a C++ header for offline tools. It does not connect to boards, modify
the bench firmware or authorize powered motion. Current project profiles remain
unmeasured and are deliberately rejected.

After the physical checks in PHYSICAL_TESTS.md, record two measured pulse/angle
anchors for each joint. Angles must use the project's joint datum and signs,
not arbitrary servo-shaft markings. Put the lower angle in angleA and the higher
in angleB; pulses can increase or decrease. Record conservative usable angle and
pulse limits inside the measured anchors, channel0/1/2 forJ1/J2/J3 and measured
true only after actual measurement. Keep the blank template intact and use a
separate recording file. Do not copy synthetic test profiles into a real record.

The tool requires all three joints and finite values, rejects missing fields,
wrong units/order/channels, equal anchors, extrapolation and inconsistent limits.
Every pulse anchor and pulse limit must remain within1450..1550us. This preserves
the present software bench window, which itself is not proof of safe motion in
an assembled leg. Wider travel requires a later measured/reviewed change; the
generic C++500..2500us absolute screen is not a travel recommendation.

Using the existing PlatformIO Python environment:

```powershell
& C:\Users\Kyle\.platformio\penv\Scripts\python.exe firmware/calibration_profiles.py firmware/measured-first-leg.json
& C:\Users\Kyle\.platformio\penv\Scripts\python.exe firmware/calibration_profiles.py firmware/measured-first-leg.json --angles 0 44.0486 78.9786
& C:\Users\Kyle\.platformio\penv\Scripts\python.exe firmware/calibration_profiles.py firmware/measured-first-leg.json --header firmware/test-output/measured-first-leg.h
```

These examples require your actual measured file; the nominal angle example is
accepted only if all three measured usable intervals contain it. Validation
and any requested mapping happen before export. An existing header is never
overwritten; choose a new filename for a revision. The header is not included
by firmware automatically. The tool previews requested microseconds, not the
physical PCA9685 tick-quantized or measured pulse widths.

Angles are normalized to float32 to match the existing C++ mapper. Anchors
that collapse at that precision are rejected; positive pulse rounding matches
C++ lround. The JSON preview shows the values used and any mapped pulses.
Passing validates mathematical consistency of the entered record; it cannot
verify that the stated measurements were physically taken.

Run `firmware/test.ps1` for the existing controller/geometry/calibration tests
and five new tool tests, including compilation of an exported synthetic header
against the actual C++ mapper. No new package dependency or hardware purchase.

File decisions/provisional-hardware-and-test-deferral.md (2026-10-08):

# Provisional hardware and deferred tests —2026-10-09

User authorizes development using MG996R/MG90S before final parts selection.
Use MG996R for all weight-bearing joints: existing CAD fits its size class.
MG90S torque is below existing joint estimates; reserve only for optional
light accessories. Published stall torque does not establish continuous duty.
PHYSICAL_TESTS.md holds the deferred checks; measured results will drive rework.

Reuse the owned5A supply for individual/staged tests, not as a qualified
three-servo or whole-robot supply. Available electronics are ESP32-S3 N16R8
and Adafruit PCA9685, so remove those purchases from the immediate BOM.
Printing access is a Creality K2 Pro. Keep calibration unset and real commands
narrow while developing offline functions.

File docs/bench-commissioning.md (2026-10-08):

# First bench test — one unmounted servo

Use electronics/bench-wiring.md and firmware/README.md. Keep the horn removed
and secure one servo. This is independent of the printed leg; neither a
successful trial nor software checks approve an assembled or loaded leg.

Record actual board/servo/PSU identities and observations in
electronics/bench-commissioning.json. Leave unknowns null. Verify the delivered
servo's voltage range from public documentation. Identify the actual PSU's
current rating; set a modest initial limit up to0.5A. If it current-limits,
stop and investigate rather than increasing it to overcome binding.

With servo power disconnected, verify actual GPIOs,3.3V logic/pullups, polarity,
common ground and external rated distribution/fuse. With no servo connected,
measure rail voltage and OE high at startup/reset; verify disabled signals are
low. OE high must exceed0.7×logic voltage and2V; low must be below0.8V.
Test the physical cutoff: it must remove both servo and buffer power. The
checker uses0.2V as a discharged-rail screen, not instantaneous response timing.

An oscilloscope or suitably rated logic analyser can measure nominal20ms PWM
period and1500us centre. Those fields are optional for the first horn-off
trial, but measure timing before wider or mounted motion. A basic multimeter
does not establish pulse width or catch fast voltage dips. No extra instrument
purchase is required just to begin the horn-off test.

After setup checks, connect one servo, enable its permitted rail, explicitly
arm one channel and try a few1450..1550us commands. Record observed rail voltage
and PSU current, current-limiting/reset behavior, response, noise and heating.
Do not put a multimeter in current mode across the supply; use the PSU display
or a correctly fused series measurement. These readings do not qualify stall
current, sustained loaded duty, transients or a three-servo supply.

Run `node electronics/evaluate-bench-commissioning.mjs`. Tests:
`node --test electronics/evaluate-bench-commissioning.test.mjs`.
The supplied record is unmeasured. Synthetic tests never populate it.
Next physical work remains four fit coupons and an unpowered leg assembly.

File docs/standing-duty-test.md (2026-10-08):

# TOR-005: provisional nominal-standing duty test requirements

2026-10-08. Status: requirements defined; NOT RELEASED for hardware execution.
This sheet defines a finite-duration holding screen for an individual actuator
at a nominal joint angle. It does not qualify a standing robot, continuous
duty, walking, transient overloads or an actuator selection.

Sources are the existing [requirements brief](actuator-requirements.md),
[nominal torque screen](static-servo-torque.md), [mass accounting](mass-accounting.md)
and [candidate evidence](../ARCHIVE/2026-10-08-superseded-design/docs/actuator-candidates.md). No manufacturer ratings are
added or refreshed in this task. All numerical test targets below are new,
provisional engineering choices, not user requirements or product ratings.

## Bounded scenario and rationale

| ID | Provisional test requirement | Rationale / interpretation |
| --- | --- | --- |
| DT-01 | Hold for 600 s without unloading after settling; three runs per released joint/load configuration on the same identified unit. | A practical ten-minute standing demonstration screen; repeats check repeatability, not production variation. |
| DT-02 | Ambient 25 +/-2 degC throughout; no forced cooling. Record mounting, enclosure and airflow. | A reproducible indoor scenario, not outdoor or maximum-temperature qualification. |
| DT-03 | Before each run, actuator case within 2 degC of ambient for 300 s; also use internal temperature if available and include its sensor uncertainty. | A reproducible cooled start; not proof every internal part has equilibrated. Do not use a fixed short rest interval instead. |
| DT-04 | Allow up to 10 s for settling after the prescribed load application ramp. Thereafter absolute joint-output angle error <=2 degrees for the full 600 s. | A provisional static accuracy target to expose droop, not a foot-placement or gait accuracy specification. |
| DT-05 | Applied torque within +/-5% of the released nonzero target throughout the hold. | Controls test comparability; target itself must include a justified uncertainty allowance. |
| DT-06 | Log angle, command, applied torque, terminal voltage and current at >=50 samples/s; case and ambient temperature at >=1 sample/s. | Resolves gross holding behavior and thermal trends. Faster current protection/acquisition is separately required if transients demand it. |

The minimum recorded full holds total 3*600 = 1800 s (30 minutes) per
configuration. Settling, ramping and cooling are additional and cannot count
toward this total. A future deployed use profile involving warm restarts or
longer sessions requires another qualification scenario. Passing these three
cooled-start runs must not be described as a continuous half-hour session.

Use the unchanged geometric nominal angles (q1,q2,q3) =
(0,44.048625674,78.978550364) degrees as reference joint positions. Servo
neutral and direction mapping must be calibrated for the eventual fixture;
these values are not direct servo commands. Use independent output-angle
measurement, not only command or internal feedback.

## Load definition: required before release

For each joint/configuration record the signed resisting torque, direction,
angle, applied-load mechanism, calibrated uncertainty, load ramp and verified
mechanical support. The actuator must balance that torque at the joint output.
No external reduction is assumed approved. A transmission requires explicit
mapping and losses; record which shaft is measured.

TOR-001 quarter/third/half-weight knee magnitudes are
0.143183/0.190911/0.286367 Nm; corresponding q1 values are
0.073550/0.098067/0.147100 Nm. These may label contact-only characterization
points, but they are not released total test torques. Hip-pitch contact zero
is not a zero-load qualification requirement. Use TOR-003 signed distal
gravity corrections with a complete, justified inventory and compatible
contact reactions; then bound load uncertainty and losses. Do not add distal
mass twice or assume the half-weight case is brief. No target load is selected
by this sheet, and no loaded run is released while it is unknown.

A zero-load baseline is diagnostic only; the percentage load criterion cannot
apply at zero. A future zero-load run needs an absolute torque tolerance.
Fixture calibration must include its own gravity, friction and lever-arm
variation with angle; hanging mass alone does not prove constant torque.

## Instrumentation and record requirements

Use synchronized timestamps and record raw values, units, calibration dates,
sensor location and uncertainty bounds. Keep internal telemetry separate from
independent angle, torque and case-temperature measurements. Document the
case sensor attachment and the surface monitored; case temperature is not
automatically winding, electronics or gear temperature.

For acceptance, use conservative interval comparisons: abs(angle error) plus
its uncertainty <=2 degrees; abs(torque-target) plus torque uncertainty
<=0.05*abs(target). Apply the same containment principle to ambient, cooled
start and all released safety limits. Define uncertainty bounds before testing;
instrument resolution alone is not a measurement uncertainty estimate.

Record unit ID, model/revision, firmware/settings, supply and current limit,
terminal voltage range, fixture/support details, load target/ramp, channel
rates, ambient, initial temperatures and per-run result. Save continuous raw
logs and a summary containing max angle error, torque extrema, current peak
and mean, voltage extrema, temperature maxima and final five-minute trend.
Trend is descriptive; a small observed slope is not a thermal-equilibrium proof.

Within scored intervals, gaps >0.04 s in fast channels or >2 s in temperature
channels invalidate that run's acceptance evidence. Missing required channels,
uncertainties or timestamps cannot yield a pass. Average log rates alone do
not demonstrate these gap requirements. Logging does not replace protective
monitoring; shutdown response must be established independently.

## Release inputs and stop conditions

| Required release input (currently OPEN) | Evidence / rule |
| --- | --- |
| Exact unit and permissible supply range | Resolve conflicting manufacturer voltage statements for that unit; choose test voltage and terminal tolerance within supported limits. |
| Signed load, uncertainty and ramp | Complete the load calculation and fixture calibration above; record duration and load direction. |
| Temperature stop thresholds | Obtain applicable internal and/or case limits with sensor locations, uncertainty and response margin. Ambient operating ranges are not case or winding limits. No universal numeric temperature threshold is invented here. |
| Current and electrical protection | Justify continuous/pulse limits and trip response for actuator, supply, wiring and connectors. Stall-current figures are not sustained-current limits. |
| Mechanical containment and isolation | Verify fixture/load capacity, supporting bearings and controlled unloading after power removal. Provide accessible independent power isolation; do not route servo power through an ESP32 board. |
| Measurement/protection implementation | Verify calibration, bandwidth, timestamps, independent stop response and all threshold values before a loaded run. |

Stop on any released thermal/electrical threshold, loss of critical monitoring,
fixture movement, uncontrolled motion, binding, visible damage or abnormal
operation. Stop when post-settling tracking error exceeds the target after
accounting for uncertainty; do not run to stall to complete the timer. Record
all events even if the unit later cools or recovers. Protection-trip limits
must include uncertainty, sensing lag and shutdown overshoot; a successful
600 s timer never overrides a trip. A safe load-retention/unloading method
must be in place before cutting actuator torque.

Ambient/load tolerance departures terminate scoring and require investigation;
do not silently delete those samples. Loss of safe monitoring requires stopping
the load as well. Candidate selection, fixture design and execution remain
separate future tasks; the table is a release dependency, not an approval request.

## Result classification and limits of the claim

- **Scoped pass:** all release inputs closed, all three complete runs satisfy
  measured criteria including uncertainty, no trips or damage, and a post-run
  unloaded function check shows no new fault relative to its recorded baseline.
  State exact unit, joint/load, voltage, mounting, ambient and cooled-start duty.
- **Fail:** tracking, thermal/electrical protection or physical integrity fails
  under otherwise valid specified conditions. An early stop is not a shorter pass.
- **Invalid/inconclusive:** missing evidence, calibration, release inputs,
  incorrect load/environment or logging gaps prevent evaluation. Preserve any
  observed failures; an invalid setup is not proof of actuator inadequacy.
  Correct the cause before a new complete run; retain the original record.

There is no result yet. Three runs on one unit provide no reliability or
manufacturing-variation guarantee. After an alarm, also meet the unit-specific
recovery requirements in [TOR-006](../ARCHIVE/2026-10-08-superseded-design/docs/actuator-protection-evidence.md); ordinary
cooled-start conditions alone do not permit restart. The reviewed ROBOTIS
manuals require at least 20 minutes cooling after an overheating alarm.
There is no automatic restart or retry authorization.
Even a scoped pass leaves TOR-002 full
load envelope, repeated motion, peaks, assembly support and whole-robot power
requirements open. Finite holding does not establish indefinite holding.

## Next bounded task (not executed)

Create a manufacturer-evidence gap closure matrix for the three TOR-004
candidates: available temperature/current limits with their precise meanings,
sensor locations and missing confirmations needed for this test. Use primary
sources; do not send inquiries, select a winner, design the fixture or run
hardware. If limits remain undocumented, report them as unresolved rather
than substituting operating ambient or stall ratings.

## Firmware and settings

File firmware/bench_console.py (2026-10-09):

"""Supervised FW-001 console. No port enumeration, auto-arm or auto-recovery."""
import argparse
import queue
import re
import threading
import time
import json
from datetime import datetime, timezone

STATUS = re.compile(r"state=(DISARMED|ARMED|FAULT) fault=(NONE|I2C|TIMEOUT|COMMAND) channel=([0-2]) pulse_us=(\d+)")
TIMING = re.compile(r"TIMING result=(PASS|CONFIG_FAILED|WRITE_FAILED|NO_SIGNAL|OUT_OF_RANGE|CLEANUP_FAILED) high_us=(\d+) period_us=(\d+) samples=([0-3])")


class ProtocolError(RuntimeError):
    pass


class Session:
    def __init__(self, transport, clock=time.monotonic, reply_timeout=0.35):
        self.transport, self.clock = transport, clock
        self.reply_timeout = reply_timeout
        self.state = None
        self.channel = 0
        self.pulse = 1500
        self.fault = "NONE"
        self.stopped = False
        self.last_poll = 0.0
        self.last_keepalive = 0.0
        self.last_timing = None

    def timing(self):
        self.exchange("status", "DISARMED", self.channel, self.pulse)
        try:
            self.transport.write(b"timing rail-off no-servos\n")
            deadline = self.clock() + 1.0  # Disarmed diagnostic only; normal deadline unchanged.
            capture = None
            while self.clock() < deadline:
                raw = self.transport.readline()
                if not raw:
                    continue
                line = raw.decode("ascii", errors="strict").strip()
                if capture is None:
                    match = TIMING.fullmatch(line)
                    if not match:
                        raise ProtocolError("Malformed timing response: " + line)
                    result, high, period, samples = match.groups()
                    high, period, samples = int(high), int(period), int(samples)
                    if high > 50000 or period > 100000 or period < high:
                        raise ProtocolError("Invalid timing measurements")
                    if samples == 0 and (high != 0 or period != 0):
                        raise ProtocolError("Measurements reported without samples")
                    if samples > 0 and not 0 < high < period:
                        raise ProtocolError("Invalid completed timing sample")
                    if result == "PASS" and not (samples == 3 and 1400 <= high <= 1600 and 19000 <= period <= 21000):
                        raise ProtocolError("Inconsistent timing PASS")
                    if result in ("CONFIG_FAILED", "WRITE_FAILED") and samples != 0:
                        raise ProtocolError("Samples reported before pulse setup")
                    if result == "NO_SIGNAL" and samples == 3:
                        raise ProtocolError("Inconsistent missing-signal sample count")
                    capture = dict(result=result, high_us=high, period_us=period, samples=samples)
                    continue
                match = STATUS.fullmatch(line)
                if not match:
                    raise ProtocolError("Missing timing cleanup status: " + line)
                state, fault, channel, pulse = match.groups()
                expected_fault = capture['result'] in ('CONFIG_FAILED', 'WRITE_FAILED', 'CLEANUP_FAILED')
                if (state, fault) != (('FAULT', 'I2C') if expected_fault else ('DISARMED', 'NONE')):
                    raise ProtocolError("Inconsistent timing cleanup state")
                if int(channel) != self.channel or int(pulse) != self.pulse:
                    raise ProtocolError("Timing changed actuator channel/pulse")
                capture.update(state=state, fault=fault, captured_at_utc=datetime.now(timezone.utc).isoformat(),
                               diagnostic_channel=15, loopback_gpio=7,
                               servo_rail_off_acknowledged=True, servos_disconnected_acknowledged=True,
                               servo_rail_voltage_measured=None)
                self.last_timing = capture
                self.state, self.fault, self.last_poll = state, fault, self.clock()
                if expected_fault:
                    raise ProtocolError("Timing bus/cleanup fault; diagnose before reconnecting")
                return json.dumps(capture)
            raise ProtocolError("Timing reply deadline exceeded")
        except (OSError, UnicodeError, ProtocolError) as error:
            self.stop()
            raise ProtocolError(str(error)) from error

    def stop(self):
        self.stopped = True
        self.state = None
        try:
            self.transport.write(b"disarm\n")
        except (OSError, RuntimeError):
            pass  # MCU timeout is the fallback; physical cutoff remains required.

    def exchange(self, command, expected_state=None, expected_channel=None, expected_pulse=None):
        if self.stopped:
            raise ProtocolError("Session stopped; diagnose and reconnect with servo rail OFF")
        try:
            self.transport.write((command + "\n").encode("ascii"))
            deadline = self.clock() + self.reply_timeout
            acknowledged = command == "status"
            while self.clock() < deadline:
                raw = self.transport.readline()
                if not raw:
                    continue
                line = raw.decode("ascii", errors="strict").strip()
                if line == "OK":
                    acknowledged = True
                    continue
                match = STATUS.fullmatch(line)
                if not match or not acknowledged:
                    raise ProtocolError("Unexpected response or device reboot: " + line)
                state, fault, channel, pulse = match.groups()
                channel, pulse = int(channel), int(pulse)
                if not 1450 <= pulse <= 1550:
                    raise ProtocolError("Unexpected pulse window")
                if (state == "FAULT") != (fault != "NONE"):
                    raise ProtocolError("Inconsistent fault state")
                if expected_state is not None and state != expected_state:
                    raise ProtocolError("Unexpected state: " + state + "/" + fault)
                if expected_channel is not None and channel != expected_channel:
                    raise ProtocolError("Unexpected channel")
                if expected_pulse is not None and pulse != expected_pulse:
                    raise ProtocolError("Unexpected pulse")
                self.state, self.fault, self.channel, self.pulse = state, fault, channel, pulse
                self.last_poll = self.clock()
                if command == "keepalive" or command.startswith(("arm ", "pulse ")):
                    self.last_keepalive = self.last_poll
                return line
            raise ProtocolError("Reply deadline exceeded")
        except (OSError, UnicodeError, ProtocolError) as error:
            self.stop()
            raise ProtocolError(str(error)) from error

    def connect(self):
        result = self.exchange("status")
        if self.state == "ARMED":
            self.stop()
            raise ProtocolError("Device already armed; use physical cutoff and reconnect")
        return result

    def command(self, text):
        if self.stopped:
            raise ProtocolError("Session stopped; diagnose and reconnect with servo rail OFF")
        if text == "status":
            return self.exchange("status", self.state, self.channel, self.pulse)
        if text == "disarm":
            # A fault remains latched after successful signal disable.
            return self.exchange("disarm", "FAULT" if self.state == "FAULT" else "DISARMED")
        if text == "reset rail-off":
            return self.exchange("reset", "DISARMED")
        if text == "timing rail-off no-servos" and self.state == "DISARMED":
            return self.timing()
        match = re.fullmatch(r"arm ([0-2])", text)
        if match and self.state == "DISARMED":
            channel = int(match.group(1))
            return self.exchange(text, "ARMED", channel, 1500)
        match = re.fullmatch(r"pulse (\d{4})", text)
        if match and self.state == "ARMED" and 1450 <= int(match.group(1)) <= 1550:
            return self.exchange(text, "ARMED", self.channel, int(match.group(1)))
        # Do not keep an armed servo alive after a mistaken operator command.
        if self.state == "ARMED":
            self.stop()
            raise ProtocolError("Invalid command while armed; signals disabled, reconnect after diagnosis")
        raise ValueError("Use status, arm 0..2, pulse 1450..1550, disarm, reset rail-off, timing rail-off no-servos or quit")

    def poll(self):
        reference = self.last_keepalive if self.state == "ARMED" else self.last_poll
        if self.clock() - reference < 0.4:
            return
        if self.state == "ARMED":
            self.exchange("keepalive", "ARMED", self.channel, self.pulse)
        else:
            self.exchange("status", self.state, self.channel, self.pulse)


def main():
    parser = argparse.ArgumentParser(description=__doc__)
    parser.add_argument("--port", required=True, help="Explicit Windows COM port; servo rail OFF before connecting")
    parser.add_argument("--timing-log", help="New JSONL file for complete diagnostic replies; never overwritten")
    parser.add_argument("--allow-legacy-pwm", action="store_true", help="Explicitly acknowledge MG996R/PCA9685 legacy operation; incompatible with ST3215")
    args = parser.parse_args()
    if not args.allow_legacy_pwm:
        parser.error("Legacy PWM console cannot control ST3215. Use --allow-legacy-pwm only for intentional legacy work.")
    import serial  # Already bundled with the existing PlatformIO Python environment.
    transport = serial.Serial(port=None, baudrate=115200, timeout=0.1, write_timeout=0.1)
    transport.dtr = False
    transport.rts = False
    transport.port = args.port
    session = Session(transport)
    commands = queue.Queue()
    timing_log = None
    last_saved = None

    def operator_input():
        try:
            while True:
                text = input().strip()
                commands.put(text)
                if text == "quit":
                    return
        except EOFError:
            commands.put("quit")

    try:
        if args.timing_log:
            timing_log = open(args.timing_log, 'x', encoding='utf-8')
        transport.open()
        # USB/serial opening can reset a board. Startup is allowed only before
        # this session, with the operator instructed to keep servo power off.
        time.sleep(1)
        transport.reset_input_buffer()
        print(session.connect())
        print("Rail OFF for wiring/reset. One unmounted servo, horn removed. Explicit arm moves to unknown centre.")
        print("status | arm 0..2 | pulse 1450..1550 | disarm | reset rail-off | timing rail-off no-servos | quit")
        threading.Thread(target=operator_input, daemon=True).start()
        while True:
            session.poll()
            try:
                text = commands.get(timeout=0.05)
            except queue.Empty:
                continue
            if text == "quit":
                break
            try:
                print(session.command(text))
            except ValueError as error:
                print(error)
            finally:
                if timing_log and session.last_timing is not None and session.last_timing is not last_saved:
                    timing_log.write(json.dumps(session.last_timing) + '\n')
                    timing_log.flush()
                    last_saved = session.last_timing
    except (ProtocolError, OSError, KeyboardInterrupt) as error:
        print("STOP:", error, "Use the physical servo-power cutoff.")
    finally:
        session.stop()
        if transport.is_open:
            transport.close()
        if timing_log:
            timing_log.close()


if __name__ == "__main__":
    main()

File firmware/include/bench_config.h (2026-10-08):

#pragma once
#include <stdint.h>
namespace bench {
constexpr uint8_t Address=0x40, Sda=4, Scl=5, Oe=6;
constexpr uint32_t OscillatorHz=25000000, TimeoutMs=1500, HealthPeriodMs=100;
constexpr uint8_t Prescale=121; // round(25MHz / (4096 * 50Hz)) - 1
constexpr uint16_t MinPulseUs=1450, CenterPulseUs=1500, MaxPulseUs=1550;
constexpr uint8_t Channels=3;
constexpr uint8_t TimingInput=7,TimingChannel=15;
constexpr uint32_t TimingWaitUs=50000;
constexpr uint16_t pulseTicks(uint16_t us) {
  return uint16_t((uint64_t(us)*OscillatorHz + uint64_t(Prescale+1)*500000) /
                  (uint64_t(Prescale+1)*1000000));
}
}

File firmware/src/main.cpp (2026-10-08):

#include <Arduino.h>
#include <Wire.h>
#include <string.h>
#include "bench_controller.h"
#include "joint_calibration.h" // offline model only; no angle command enabled
#include <initializer_list>
#include "leg_geometry.h" // offline FK only; no hardware position command
#include "leg_inverse.h" // offline IK only; no hardware position command
#include "leg_plan.h" // side-effect-free preparation only; never sent to servos
#include "bench_command.h"
#include "pca9685.h"
#include "pwm_timing.h"
#include "voltage_monitor.h"

struct WireBus {
  bool write(uint8_t reg,const uint8_t* data,size_t n) {
    Wire.beginTransmission(bench::Address);
    if(Wire.write(reg)!=1 || Wire.write(data,n)!=n) { Wire.endTransmission(); return false; }
    return Wire.endTransmission()==0;
  }
  bool read(uint8_t reg,uint8_t& value) {
    Wire.beginTransmission(bench::Address);
    Wire.write(reg);
    if(Wire.endTransmission(false)!=0) return false;
    if(Wire.requestFrom(bench::Address,uint8_t(1))!=1) return false;
    value=Wire.read(); return true;
  }
  void waitUs(unsigned us) { delayMicroseconds(us); }
} bus;
bench::Pca9685<WireBus> pwm(bus);
struct Hardware {
  void disable(bool disabled){digitalWrite(bench::Oe,disabled?HIGH:LOW);}
  bool initialize(){return pwm.initialize();}
  bool allOff(){return pwm.allOff();}
  bool healthy(){return pwm.healthy();}
  bool pulse(uint8_t c,uint16_t us){return pwm.pulse(c,us);}
} hardware;
bench::Controller<Hardware> controller(hardware);
struct TimingHardware {
  void disable(bool disabled){hardware.disable(disabled);}
  bool healthy(){return pwm.healthy();}
  bool allOff(){return pwm.allOff();}
  bool testPulse(){return pwm.loopbackPulse();}
  uint32_t measure(bool high,uint32_t timeout){return pulseIn(bench::TimingInput,high?HIGH:LOW,timeout);}
} timingHardware;
struct VoltageHardware {
  bool begin(){analogReadResolution(12);analogSetPinAttenuation(bench::VoltageInput,ADC_11db);return true;}
  bool read(uint32_t& raw,uint32_t& mv){
    raw=analogRead(bench::VoltageInput);mv=analogReadMilliVolts(bench::VoltageInput);return true;
  }
  void waitMs(unsigned ms){delay(ms);}
} voltageHardware;
char line[48]; size_t used=0; bool overflow=false;

void status() {
  const char* names[]={"DISARMED","ARMED","FAULT"};
  const char* faults[]={"NONE","I2C","TIMEOUT","COMMAND"};
  Serial.printf("state=%s fault=%s channel=%u pulse_us=%u\n",
    names[int(controller.state())],faults[int(controller.fault())],
    controller.channel(),controller.pulse());
}
void command(const char* text) {
  bool ok=false;
  const uint32_t now=millis(); controller.tick(now);
  const auto parsed=bench::parseCommand(text);
  switch(parsed.command) {
    case bench::Command::Status:status();return;
    case bench::Command::Disarm:ok=controller.disarm();break;
    case bench::Command::Reset:ok=controller.reset();break;
    case bench::Command::Keepalive:ok=controller.keepalive(now);break;
    case bench::Command::Arm:ok=controller.arm(uint8_t(parsed.value),now);break;
    case bench::Command::Pulse:ok=controller.move(parsed.value,now);break;
    case bench::Command::Timing: {
      if(controller.state()!=bench::State::Disarmed) {controller.badCommand();break;}
      const auto result=bench::measurePwmTiming(timingHardware);
      const char* names[]={"PASS","CONFIG_FAILED","WRITE_FAILED","NO_SIGNAL","OUT_OF_RANGE","CLEANUP_FAILED"};
      if(result.status==bench::TimingStatus::ConfigFailed || result.status==bench::TimingStatus::WriteFailed ||
         result.status==bench::TimingStatus::CleanupFailed)controller.externalBusFailure();
      Serial.printf("TIMING result=%s high_us=%lu period_us=%lu samples=%u\n",
        names[int(result.status)],(unsigned long)result.highUs,(unsigned long)result.periodUs,result.samples);
      status();return;
    }
    case bench::Command::Voltage: {
      const auto result=bench::measureVoltage(controller,voltageHardware);
      const char* names[]={"READING","LOW_OR_DISCONNECTED","ADC_OUT_OF_RANGE","READ_FAILED","NOT_DISARMED","PREFLIGHT_FAILED"};
      Serial.printf("VOLTAGE result=%s adc_mv=%lu input_mv=%lu spread_mv=%lu raw=%lu samples=%u calibrated=false\n",
        names[int(result.status)],(unsigned long)result.adcMv,(unsigned long)result.inputMv,
        (unsigned long)result.spreadMv,(unsigned long)result.rawAverage,result.samples);
      status();return;
    }
    default:controller.badCommand();break;
  }
  Serial.println(ok?"OK":"REJECTED"); status();
}
void setup() {
  digitalWrite(bench::Oe,HIGH); pinMode(bench::Oe,OUTPUT);
  pinMode(bench::TimingInput,INPUT_PULLDOWN);
  Serial.begin(115200);
  Wire.begin(bench::Sda,bench::Scl,100000); Wire.setTimeOut(10);
  controller.reset();
  Serial.println("Quadra bench only: rail OFF before wiring; status/arm 0..2/pulse 1450..1550/keepalive/disarm/reset");
  status();
}
void loop() {
  controller.tick(millis());
  // Bound work per loop so a serial flood cannot prevent timeout/health checks.
  for(unsigned count=0;count<32 && Serial.available();++count) {
    char c=char(Serial.read());
    if(c=='\r') continue;
    if(c=='\n') {
      if(overflow){controller.badCommand();Serial.println("REJECTED oversized line");}
      else if(used){line[used]=0;command(line);}
      used=0;overflow=false;
    } else if(c<' ' || c>'~') overflow=true;
    else if(!overflow && used<sizeof(line)-1) line[used++]=c;
    else overflow=true;
  }
  delay(1);
}

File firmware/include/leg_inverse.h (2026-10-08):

#pragma once
#include <float.h>
#include <stdint.h>
#include "leg_geometry.h"
namespace bench {
struct JointAngles { double q1=0,q2=0,q3=0; };
struct JointBounds {
  JointAngles minimum{-25,20,60},maximum{30,55,90}; // unpowered geometric envelope only
};
enum class InverseStatus { Unique, Ambiguous, Unreachable, OutsideBounds,
  Singular, InvalidGeometry, InvalidTarget, InvalidBounds };
struct InverseResult {
  InverseStatus status=InverseStatus::Unreachable;
  uint8_t count=0;
  bool singular=false;
  JointAngles solutions[4]{};
};
inline double normalizedAngle(double angle) {
  double r=fmod(angle+180,360);if(r<0)r+=360;return r-180;
}
inline bool fitAngle(double angle,double minimum,double maximum,double& output) {
  for(double value:{angle-360,angle,angle+360}) {
    if(value>=minimum-1e-8 && value<=maximum+1e-8) {
      output=value<minimum?minimum:value>maximum?maximum:value;return true;
    }
  }
  return false;
}
inline InverseResult inverseKinematics(const LegGeometry& g,const Point3& target,
                                      const JointBounds& bounds={}) {
  InverseResult result;
  LegPose check;
  if(!forwardKinematics(g,0,0,0,check)) {result.status=InverseStatus::InvalidGeometry;return result;}
  for(double value:{target.x,target.y,target.z})if(!isfinite(value)) {
    result.status=InverseStatus::InvalidTarget;return result;
  }
  const double lo[]={bounds.minimum.q1,bounds.minimum.q2,bounds.minimum.q3};
  const double hi[]={bounds.maximum.q1,bounds.maximum.q2,bounds.maximum.q3};
  for(unsigned i=0;i<3;++i)if(!isfinite(lo[i])||!isfinite(hi[i])||lo[i]>hi[i]||lo[i]<-180||hi[i]>180) {
    result.status=InverseStatus::InvalidBounds;return result;
  }
  const double d=g.pitchFloorYmm+g.referenceAxialMm;
  const double radius=hypot(target.y,target.z),delta=radius*radius-d*d;
  if(!isfinite(delta))return result;
  const double tolerance=32*DBL_EPSILON*fmax(1,fmax(radius*radius,d*d));
  if(delta < -tolerance)return result;
  if(radius==0 && d==0){result.status=InverseStatus::Singular;result.singular=true;return result;}
  const double height=sqrt(fmax(0,delta));
  constexpr double deg=180/3.14159265358979323846;
  bool geometricallyReachable=false;
  for(double vertical:{-height,height}) {
    const double q1=normalizedAngle((atan2(target.z,target.y)-atan2(vertical,d))*deg);
    const double p=g.pitchVerticalMm-vertical,w=target.x-g.pitchForwardMm;
    double cosine=(p*p+w*w-g.upperMm*g.upperMm-g.lowerMm*g.lowerMm)/(2*g.upperMm*g.lowerMm);
    if(!isfinite(cosine)||cosine<-1-64*DBL_EPSILON||cosine>1+64*DBL_EPSILON)continue;
    geometricallyReachable=true;
    cosine=fmax(-1,fmin(1,cosine)); // machine-roundoff guard, not target projection
    for(double knee:{acos(cosine),-acos(cosine)}) {
      const double q2=normalizedAngle((atan2(w,p)+atan2(g.lowerMm*sin(knee),g.upperMm+g.lowerMm*cos(knee)))*deg);
      const double q3=normalizedAngle(knee*deg);
      JointAngles candidate;
      if(!fitAngle(q1,lo[0],hi[0],candidate.q1)||!fitAngle(q2,lo[1],hi[1],candidate.q2)||
         !fitAngle(q3,lo[2],hi[2],candidate.q3))continue;
      if(!forwardKinematics(g,candidate.q1,candidate.q2,candidate.q3,check))continue;
      if(hypot(hypot(check.footReference.x-target.x,check.footReference.y-target.y),
               check.footReference.z-target.z)>1e-7)continue;
      bool duplicate=false;
      for(unsigned i=0;i<result.count;++i) {
        const auto& old=result.solutions[i];
        if(fabs(normalizedAngle(old.q1-candidate.q1))<1e-7 &&
           fabs(normalizedAngle(old.q2-candidate.q2))<1e-7 &&
           fabs(normalizedAngle(old.q3-candidate.q3))<1e-7)duplicate=true;
      }
      if(!duplicate && result.count<4) {
        result.solutions[result.count++]=candidate;
        if(height<1e-9 || fabs(sin(knee))<1e-8)result.singular=true;
      }
    }
  }
  result.status=result.count==1?InverseStatus::Unique:result.count>1?InverseStatus::Ambiguous:
    geometricallyReachable?InverseStatus::OutsideBounds:InverseStatus::Unreachable;
  return result;
}
}

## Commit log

2026-10-08 Initial committ
    [hobby-joint-assembly.scad, hobby-joint-assembly.stl, hobby-joint-bearing-coupon.stl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]
2026-10-08 Add supported three-DOF bench leg and prototype build pack
    [hobby-joint-front-arm.stl, prototype-j1-carrier.scad, prototype-j1-carrier.stl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]
2026-10-08 Preserve exact release mesh hashes across Git checkouts
    [hobby-joint-assembly.stl, hobby-joint-bearing-coupon.stl, hobby-joint-bridge.stl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]
2026-10-08 Add unpowered prototype fit evaluator
2026-10-08 Prepare isolated single-leg bench power and wiring
2026-10-08 Add tested individual-servo bench firmware
2026-10-08 Add supervised servo bench console and reproducible local tests
2026-10-08 Prepare measured commissioning gate for first servo trial
2026-10-08 Defer physical checks and develop offline joint calibration for N16R8
2026-10-08 Add independently checked CAD-matched bench-leg forward kinematics
    [geometry-reference-probe.scad]
2026-10-08 Add bounded offline inverse kinematics with explicit branches and singular flags
2026-10-08 Prepare atomic calibrated one-leg plans without hardware motion
2026-10-08 Add explicit board-only PWM timing diagnostic with bounded cleanup
2026-10-08 Add provisional four-leg placement and packaging study
    [prototype-four-leg-study.scad]
2026-10-08 Add printable chassis mounts with support-rib clearance
    [prototype-chassis-assembly.scad, prototype-chassis-deck.stl, prototype-chassis-mount-left.stl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]
2026-10-08 Correct bench adapter support-rib clearance and revise checkpoint
    [hobby-joint-assembly.scad, hobby-joint-bearing-coupon.stl, hobby-joint-bearing-parts.scad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]
2026-10-08 Resolve physical handed parts and rigid four-leg assembly
    [prototype-chassis-mount-left.stl, prototype-chassis-mount-right.stl, prototype-chassis-mount.scad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]
2026-10-08 Package physically placeable bench carrier and saddle
    [hobby-joint-assembly.scad, hobby-joint-bearing-coupon.stl, hobby-joint-bearing-parts.scad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]
2026-10-08 Prototype integrated pitch forks with clearance and mass checks
    [prototype-pitch-fork-assembly.scad, prototype-pitch-fork-lower-mirrored.stl, prototype-pitch-fork-lower.stl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]
2026-10-08 Integrate physical pitch forks into the three-DOF leg
    [fork-leg-parts.scad, prototype-fork-leg-assembly.scad, prototype-fork-leg-probe.scad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]
2026-10-08 Add side-on fork fit coupon and print checks
    [prototype-fork-fit-coupon.scad, prototype-fork-fit-coupon.stl]
2026-10-08 Validate and export measured first-leg calibration profiles offline
2026-10-08 Expose calibrated foot-target planning through an offline CLI
2026-10-08 Capture supervised board-only PWM timing in the host console
2026-10-08 Prototype integrated hip carrier with physical placement checks
    [prototype-integrated-hip-assembly.scad, prototype-integrated-hip-mirrored.stl, prototype-integrated-hip-probe.scad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]
2026-10-08 Complete integrated four-leg prototype plan and mass record
    [integrated-four-leg-parts.scad, integrated-four-leg-probe-data.scad, prototype-integrated-four-leg-assembly.scad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]
2026-10-08 Release integrated single-leg prototype build checkpoint
    [hobby-joint-bearing-coupon.stl, hobby-joint-bearing-parts.scad, hobby-joint-bridge.scad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]
2026-10-08 Add universal electronics attachment deck option
    [prototype-electronics-deck.scad, prototype-electronics-deck.stl]
2026-10-08 Plan provisional twelve-servo signal and power harness
2026-10-08 Compare commodity robot power options without locking purchases
2026-10-08 Define perfboard buffer carrier and prototype sourcing preferences
2026-10-08 Shortlist DigiKey parts for perfboard prototype buffers
2026-10-08 Add disarmed perfboard voltage measurement diagnostic
2026-10-08 Add removable printed two-tier electronics carrier
    [prototype-electronics-carrier-base.stl, prototype-electronics-carrier-shelf.stl, prototype-electronics-carrier.scad]
2026-10-09 Simplify electronics mounting with lightweight single-level sleds
    [prototype-electronics-sled-esp32.stl, prototype-electronics-sled-pca9685.stl, prototype-electronics-sled-perfboard.stl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]
2026-10-09 Treat robot mass target separately from servo-qualified capacity
2026-10-09 Redesign first leg for ST3215 feedback servos and 3S battery
    [ST3215.dxf, ST3215.step, st3215-battery-tray.scad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]
2026-10-09 Align battery tray export with validated source report
    [st3215-battery-tray.stl]
2026-10-09 Review ST3215 prototype risks and development priorities
2026-10-09 Guard stale ST3215 artifacts and incompatible PWM entry points
    [st3215-battery-tray.stl, st3215-clamp-bottom.stl, st3215-clamp-top.stl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]
2026-10-09 Refine ST3215 leg fit controls and printable clamp coupons
    [st3215-battery-tray.stl, st3215-clamp-bottom.stl, st3215-clamp-fit29-bottom.stl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]
2026-10-09 Add printable ST3215 four-leg chassis and central battery layout
    [st3215-battery-tray.stl, st3215-chassis-body.stl, st3215-chassis-deck.stl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]
2026-10-09 Add ST3215 single-servo feedback bench firmware
